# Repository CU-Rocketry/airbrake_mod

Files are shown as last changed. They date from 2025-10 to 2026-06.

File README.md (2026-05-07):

# Air Brakes
The Air Brakes control system primarily manages the vehicle’s energy state throughout its unpowered ascent phase of 
flight by modulating the rocket’s aerodynamic drag profile in a bid to regulate its apogee to the specified target of 
10,000 ft AGL with a tolerance of ± 500 ft. At the 2025 IREC, Clarkson University Rocketry (CUR) launched Veðrfölnir, 
last year’s rocket and Air Brakes iteration, to an apogee of 10,352 ft, successfully achieving our apogee target goal. 
This year, CUR returns with the improvements detailed below with the intention of again improving our apogee accuracy through further control system development.

The complete Air Brakes system includes a mechanical assembly engineered for fail-safe, symmetric brake flap deployment, a refined electronics hardware design, 
and an improved control algorithm responsible for state estimation of the rocket, apogee prediction, and continuously variable PI-controller generating actuation commands. 
Throughout the development cycle, the team focused on building off of prior successes and expanding novel concepts, while ensuring Air Brakes safety and working 
within manufacturability and integration constraints.

## Mechanical Design
The Air Brakes mechanical design source files are not included in this repository.

The design features four symmetrically arranged brake flaps whcih are deployed radially into the airstream surrounding the rocket body. 
The current revision has a total wetted area of 10.18 in², resulting in a near doubling of the total drag force on the rocket to a maximum of 222.6 lbf if deployed after burnout.
The brake flaps ride along linear rails to bear the aerodynamic load and are deployed by a high-speed, high-torque, and dust-rated servo motor, which rotates a central hub connected by linkages to the flaps. 
The chosen servo was tested under load to fully deploy in only 0.3 seconds, and has been upgraded since last year with a feedback signal allowing the microcontroller to measure true deployment as well as detect and mitigate brake flap binding. 
The system continues to integrate compactly within the rocket airframe, adding only 1.75 in to the rocket’s overall length while featuring an increased upper coupler bonded length of 2 in.

Prior revisions of the Air Brakes module have been flown at the Spaceport America Cup and Midland, TX Interneational Rocket Engineering Competition (IREC) events.

## Control System PCB
KiCad 9 source files for the control system PCB are included within the `pcb/` directory. A hierarchical structure is used for schematic diagrams, and schematic symbols as well as PCB footprints
created by the team or downloaded from the manufacturer are included within the `pcb/kicad-library` submodule, which may need to be synced as part of the setup process.

The air brakes electronics feature a four layer, single sided control system PCB with the following considerations taken to achieve our safety critical design constraints while implementing an STM32H730 MCU to perform state estimation and control system tasks, handle user interface, and command the brake flap actuation servo.
The PCB form factor has changed since the revision flown at IREC 2025: the 18650 battery holders have been removed in favor of an externally connected battery, allowing the board size to be halved and battery located beside the PCB.

Power for the system is supplied by a 7.4V (2S) 3000 mAh lithium-ion battery connected to the board by an XT30 connector.
The system has a power-on battery life of at least 12 hr based on battery current draw measurements for an onboard shunt resistor-based current monitor IC.
System power status is determined using an on-chip ADC peripheral of the MCU, reading both the current sense IC output and level of a 2.75:1 voltage divider to convert the battery voltage to fit within the ADC's 3.3V range.

This control system PCB includes power distribution to the servo motor, which may be switched on or off by an on-board transistor under software control.
The servo motor is connected with a four pin latching connector.
As an iterative improvement to our prior design with experience from IREC 2025, the servo has been substituted for an otherwise similar model with position feedback on an additional wire carrying an analog voltage signal corresponding to the servo shaft angle, which may be read by the MCU with an ADC peripheral.

The system includes multiple physical controls including an on-off slide switch, an eight-position rotary mode selector switch, and four tactile switches with alternative functionality based on current mode.
Available modes include startup, testing of user interface, servo, flash, sensors, and control system, a launch detect state to be enabled at the pad, and a data offloading state.
The power switch controls the buck converter enable signal, and includes an RC (resistor-capacitor) filter (time constant tau=0.135 s) to prevent switch bouncing from temporarily disabling the buck converter and resetting the system.
In addition, two RGB LEDs and a passive buzzer (allowing for frequency control) are implemented on the PCB to give internally and externally accessible go/no-go feedback.

To act as inputs to the control system, MEMS sensors from STMicroelectronics were chosen for their pre-existing driver compatibility with STM32 MCUs.
Each sensor also has commonality with the SRAD flight computer developed in parallel, allowing electrical schematics, PCB layout, and code to be shared between the systems towards integrating them in the future.
The LPS22DF barometer was chosen for its 24 bit at 200 Hz pressure output capability, and 22,000G shock survivability. A new inertial measurement unit (IMU), the LSM6DSV80X, was selected for its dual 16 bit accelerometer channels: a low-G channel measuring up to 16G and high-G channel measuring up to 80G in addition to including a 4000 dps, 16 bit gyroscope. 
Together with the final sensor, an IIS2MDC 16 bit magnetometer compass IC, a full complement 9-axis IMU can be implemented in software.

The control system PCB retains a USB Type-C connector for power and data transfer, as well as an on-board 128 MBit flash memory, which emulates a USB flash drive when plugged into a computer in data offloading mode.

## State Estimation and Control System

The air brakes control system was prototyped as a subsystem within the rocket plant Simulink model, which was
later ported to C code to run on the air brakes system’s MCU, taking advantage of the device’s double precision FPU
(Floating Point Unit) as well as using ARM-optimized CMSIS-DSP functions for matrix processing. For clarity and
brevity, the control system functionality is described in this report referencing the Simulink model.
Factoring in the orientation of the implemented sensors on the PCB relative to the body frame was crucial for the
interpretation of IMU and magnetometer data. Unit conversions were also implemented in this sensor data pre-processing step using conversion
factors to common SI units.
The state estimation subsystem implements Madgwick filter sensor fusion on IMU and magnetometer data to
estimate a body to inertial quaternion rotation. The magnetometer assists in estimating the orientation of the rocket by
recording magnetic flux density to the end of determining the magnetic north direction, though it contributes to the
Madgwick filter at a slower update rate through a separate function due to its limited ODR (Output Data Rate). This
quaternion is normalized to a unit vector, and a vector rotation is then performed, where the rotated vector represents 
estimated acceleration in the inertial frame, a necessary input to the next stage of the
control system: the Kalman filter. A two-state Kalman filter was implemented to estimate the rocket’s current altitude
and vertical velocity, and in a similar way to the Madgwick filter, the Kalman filter is implemented as two separate
functions to allow the prediction step—based on high-ODR accelerometer data—to be decoupled from the correction
step which relies on the slower barometer data updates.
The final component of the state estimation subsystem, a launch detect function, was incorporated to identify the
beginning of flight, and differentiate between unintentional movement of the rocket and actual launch. If the rocket
experiences a significant acceleration in the body +X direction and increase in barometric altitude, launch detect is
triggered. When launch detect is triggered, the time since system power on is stored as the launch time, and the mission
elapsed time afterwards is calculated by subtracting the launch time from the time since power on.
The air brakes control system relies on the data from the Kalman filter to predict the rocket’s eventual apogee
using a simplified lightweight model for a projectile with drag, which is used (when the target apogee is subtracted) as the
error input to the controller.
The air brakes deployment controller follows a typical PID (Proportional-Integral-Derivative) structure, but with the
derivative component removed (i.e. gain set to zero) to avoid over correction or oscillation that may make achieving
the target apogee impossible. Instead, small Kp and Ki gains are used to drive the servo motor to decrease the error
function, which is calculated as the difference between the predicted apogee and 3048 m target apogee. The integral
term includes both anti-windup protection, limiting its contribution to deployment to a maximum of 50% and also
resetting the integral term any time the predicted apogee is below the target apogee.
An air brakes lockout subsystem places checks on the controller’s output to the brake actuation servo, preventing
deployment or retracting the brakes if the rocket is still in the powered ascent phase of flight, if the vertical
velocity is slow and the air brakes are ineffective, or if the rocket’s attitude exceeds 30◦ from launch elevation.

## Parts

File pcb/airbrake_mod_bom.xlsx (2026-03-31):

Reference | Qty | MPN
BZ1 | 1 | CEM-1203(42)
C1,C2 | 2 | GRT188R61H225KE13D
C3,C26 | 2 | GRM188R61E475KE11D
C4,C9 | 2 | CL10C150JB8NNNC
C5,C7,C8,C10,C11,C13,C14,C15,C20,C23,C24,C25,C27,C28,C29,C31 | 16 | CL10B104KB8NNWC
C6,C12,C18 | 3 | CL10A105KA8NNNC
C16,C22 | 2 | CL21A226MAYNNNE
C17 | 1 | CL10B104KB8NNWC
C19 | 1 | CL10B104KB8NNWC
C21 | 1 | CL10C100JB8NNNC
C30 | 1 | CL10A224KB8NNNC
C32 | 1 | ZRB18AR61C106ME01L
D1,D4 | 2 | SS12
D2,D8,D9 | 3 | FC-1608SXK-620H08
D3,D5 | 2 | 19-237/R6GHBHC-M01/2T
D6,D7 | 2 | ESDA5V3SC5
FB1 | 1 | BLM18AG601SN1D
J1 | 1 | XT30PW-M
J2 | 1 | UJ20-C-H-G-SMT-P16-TR
J3 | 1 | 0436500415
J4 | 1 | 2147511041
J6 | 1 | 3220-14-0100-00
L1 | 1 | SLO0624H3R3MTT
Q1,Q2,Q4,Q6 | 4 | NTR4003N
Q3,Q5 | 2 | SI3407DV-T1-GE3
R1 | 1 | RC0603FR-0747RL
R2,R4,R8,R9,R11,R16,R22,R23,R24,R26,R28,R33,R40,R41,R42 | 15 | RC0603FR-0747KL
R3,R5,R10,R19,R20,R21,R25,R27,R29,R30,R31,R35,R36,R39,R43,R44 | 16 | RC0603JR-07150RL
R6 | 1 | RC0603FR-0747KL
R7 | 1 | RC0603FR-0782KL
R12 | 1 | RT0603BRD07135KL
R13,R15 | 2 | AC0603FR-0730KL
R14 | 1 | PA0805FRE7W0R002L
R17,R18 | 2 | RC0603FR-075K1L
R32,R34,R37,R38 | 4 | RC0603FR-0747RL
S1 | 1 | RDS4-8S-1012-73-RA-254-D-67
SW1,SW2,SW4,SW5,SW6,SW7 | 6 | SKRPADE010
SW3 | 1 | SLW-864574-5A-RA-N-D
TP1,TP2,TP3,TP4,TP5,TP6,TP7,TP8,TP9,TP10,TP11,TP12,TP13,TP14,TP15,TP16,TP17,TP18,TP19,TP20,TP21,TP22,TP23,TP24,TP25,TP26,TP27,TP28,TP29,TP30,TP31,TP32,TP33,TP34,TP35,TP36,TP37 | 37 | RCUCTE
U1 | 1 | STM32H730VBT6
U2 | 1 | TPS561246DRLR
U3 | 1 | ZXCT180A4W5
U4 | 1 | USBLC6-2SC6
U5 | 1 | W25Q128JVSIQ
U6 | 1 | LPS22DFTR
U7 | 1 | LSM6DSV80XTR
U8 | 1 | IIS2MDCTR
Y1 | 1 | ECS-160-12-33B2Q-JES-TR3

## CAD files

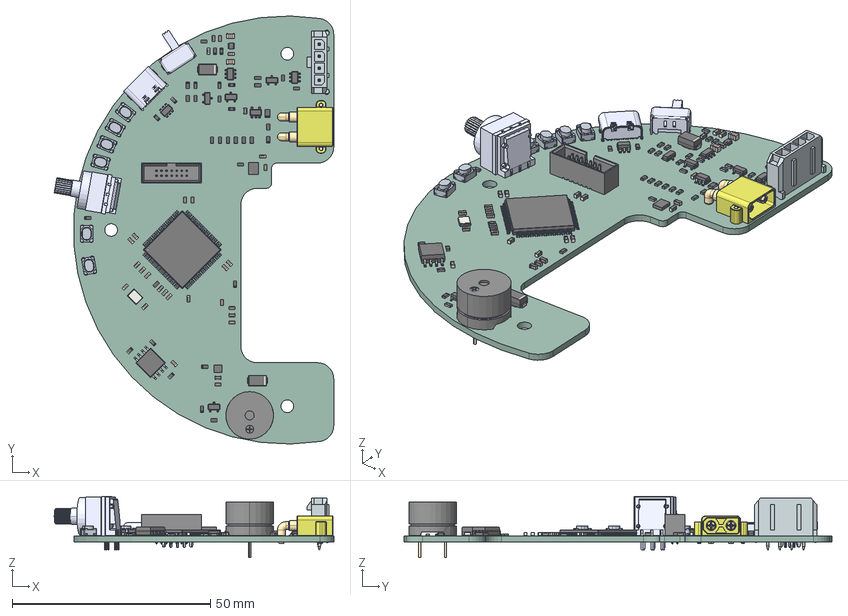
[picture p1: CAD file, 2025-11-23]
pcb/airbrake_mod.step
70.5 x 107.9 x 15.4 mm
C_0603_1608Metric x 28
R_0603_1608Metric x 35
PTS815SJM250SMTRLFS_PART1 x 6
PTS815SJM250SMTRLFS_PART2 x 6
PTS815SJM250SMTRLFS_PART3 x 6
C_0805_2012Metric x 2
Crystal_SMD_3225-4Pin_3.2x2.5mm
TSOP-6_1.65x3.05mm_P0.95mm x 2
L_0603_1608Metric
SOT-23-6
D_SMA x 2
SOT-23-3 x 4
R_0805_2012Metric
SOIC-8_5.3x5.3mm_P1.27mm
kicad_embedded_C4738336200E169EB35A505B1D9200E8
UJ20-C-H-G-SMT-P16-TR
Molex_436500415
LGA-14_3x2.5mm_P0.5mm_LayoutBorder3x4y
SOT-563
RDS4-1012-73-RA HOUSING
RDS4-1012-73-RA-254 HOUSING
RDS4-73-8 POSITION
Buzzer_SameSky_CEM-1203_42
3220-xx-0100-00 body_14
Pin^3220-xx-0100-00 x 14
LQFP-100_14x14mm_P0.5mm
ST_HLGA-10_2x2mm_P0.5mm_LayoutBorder3x2y
SOT-23-5
XT30PW-M
airbrake_mod_PCB

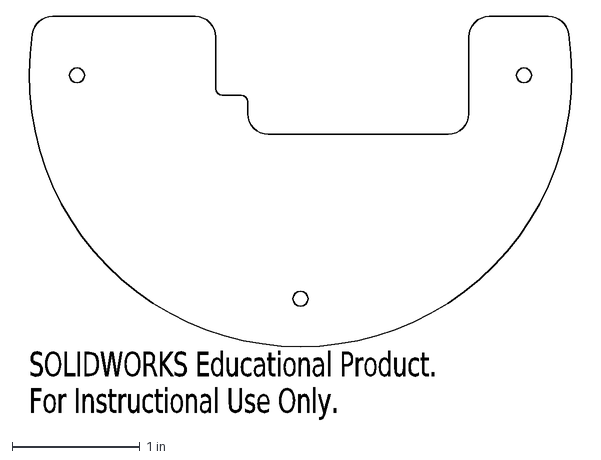
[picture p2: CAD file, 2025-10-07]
pcb/outline.dxf
SOLIDWORKS Educational Product.
For Instructional Use Only.

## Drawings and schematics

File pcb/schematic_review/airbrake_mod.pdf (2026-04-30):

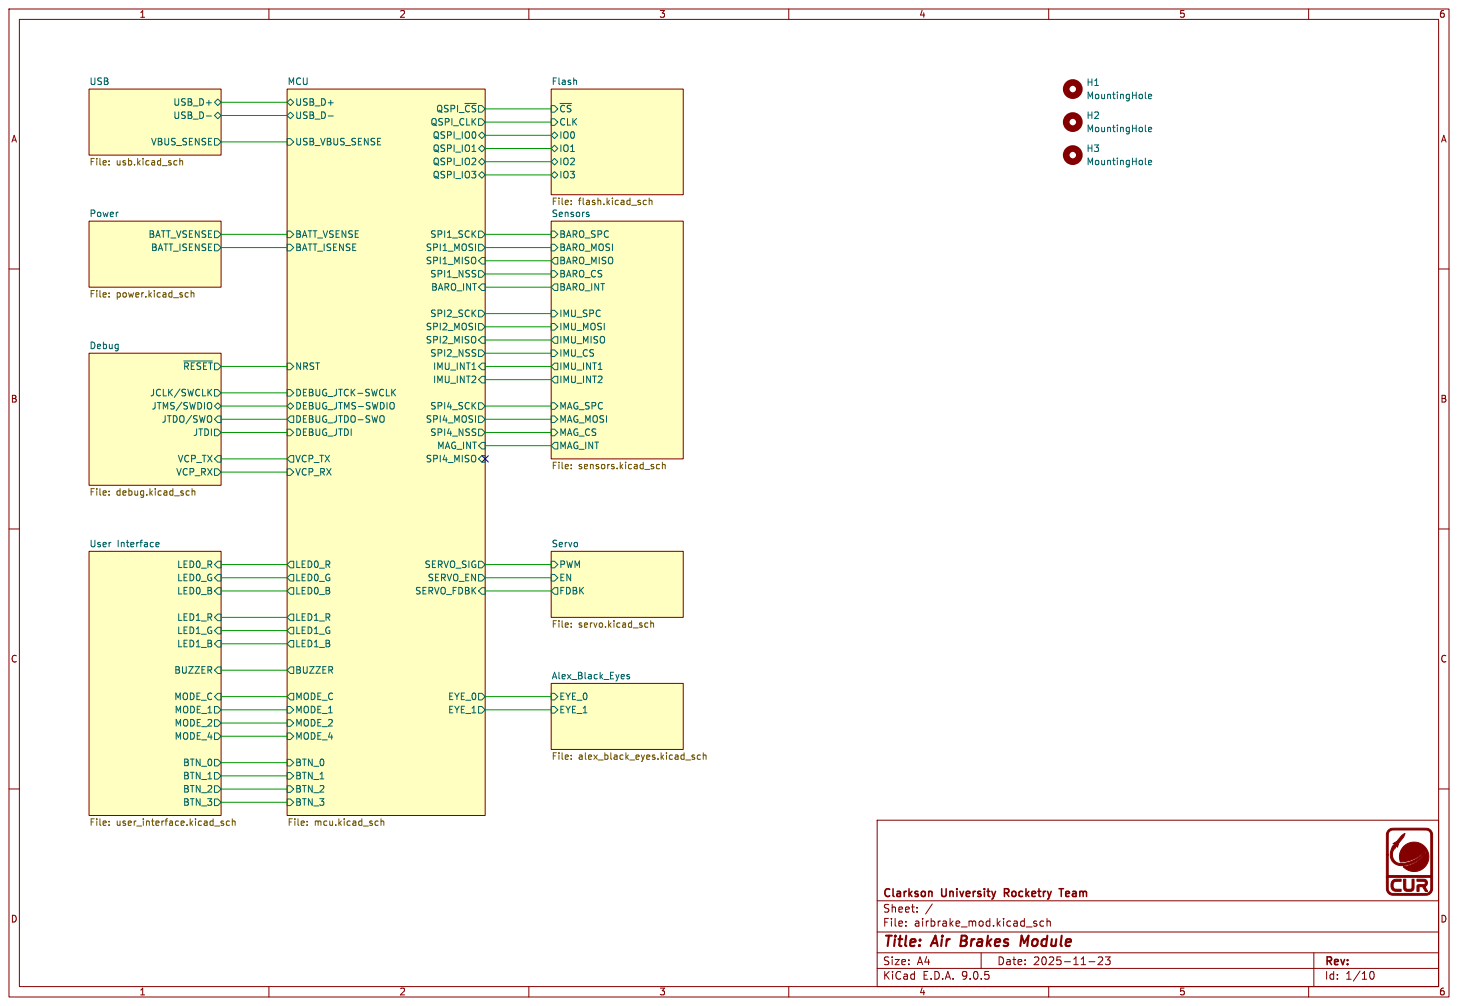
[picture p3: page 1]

Servo File: servo.kicad_sch EYE_1 EYE_0 Alex_Black_Eyes File: alex_black_eyes.kicad_sch

Id: 1/10 Title: Air Brakes Module

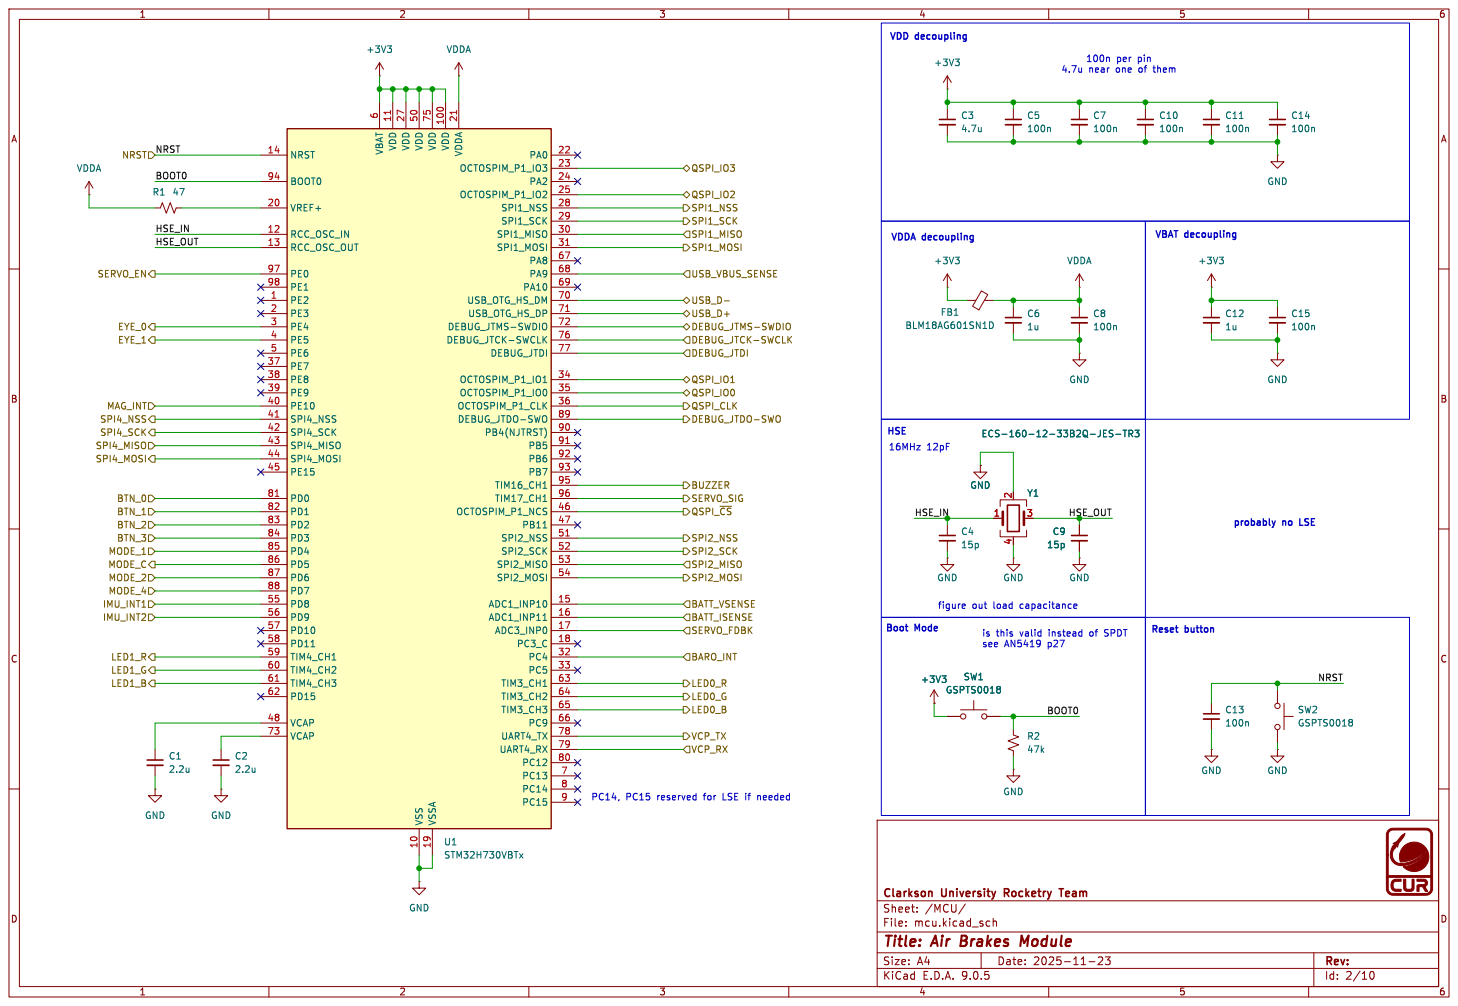
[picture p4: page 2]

100n per pin
4.7u near one of them

VBAT decoupling Boot Mode HSE

16MHz 12pF PC14, PC15 reserved for LSE if needed

is this valid instead of SPDT
see AN5419 p27

Id: 2/10 Title: Air Brakes Module

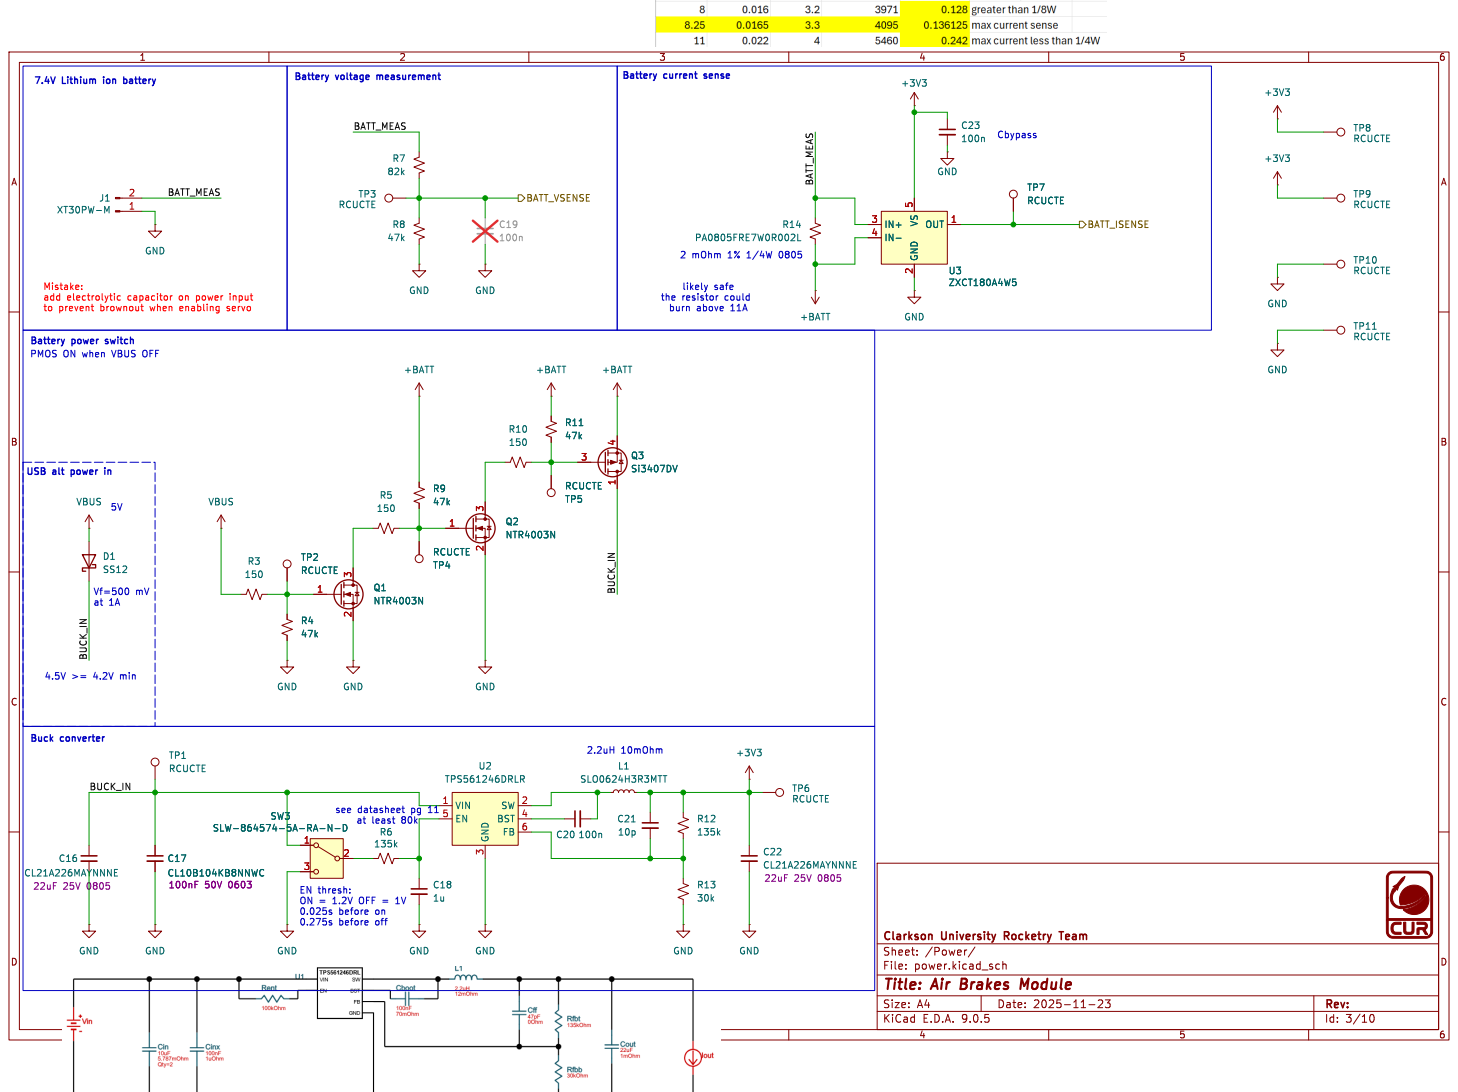
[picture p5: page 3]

USB alt power in PMOS ON when VBUS OFF Battery power switch

at 1A CinC: 20 þÿ¼F- 20 þÿ¼F ESR: 1 þÿm©- 20 þÿm©

at least 80k EN thresh: ON = 1.2V OFF = 1V

Id: 3/10 Title: Air Brakes Module

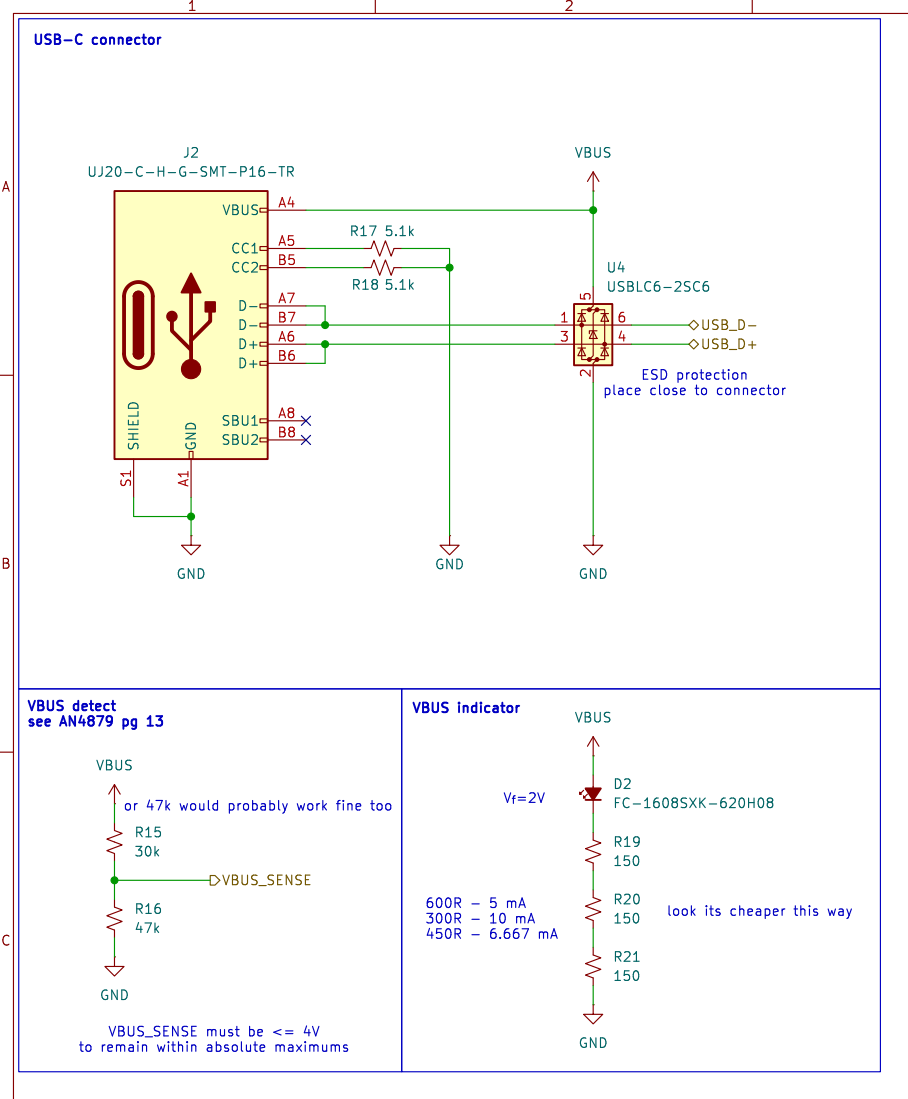
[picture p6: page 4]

look its cheaper this way ESD protection

Id: 4/10 Title: Air Brakes Module

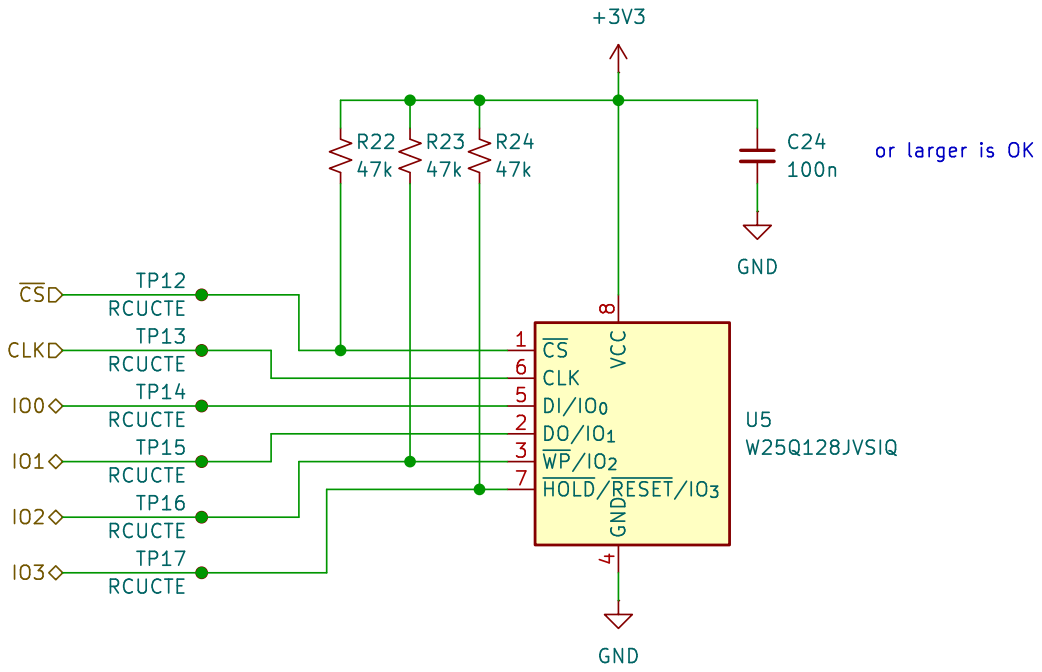
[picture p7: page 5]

or larger is OK

Id: 5/10 Title: Air Brakes Module

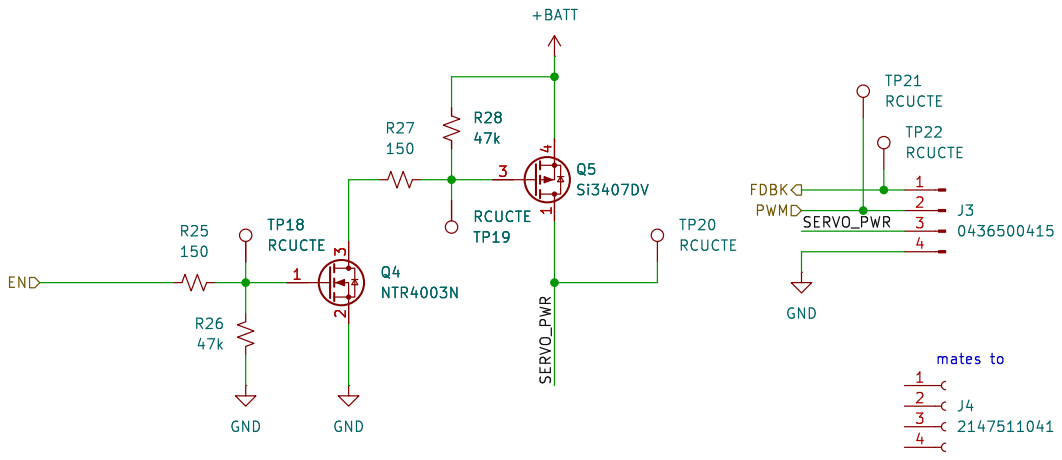
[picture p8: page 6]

Id: 6/10 Title: Air Brakes Module

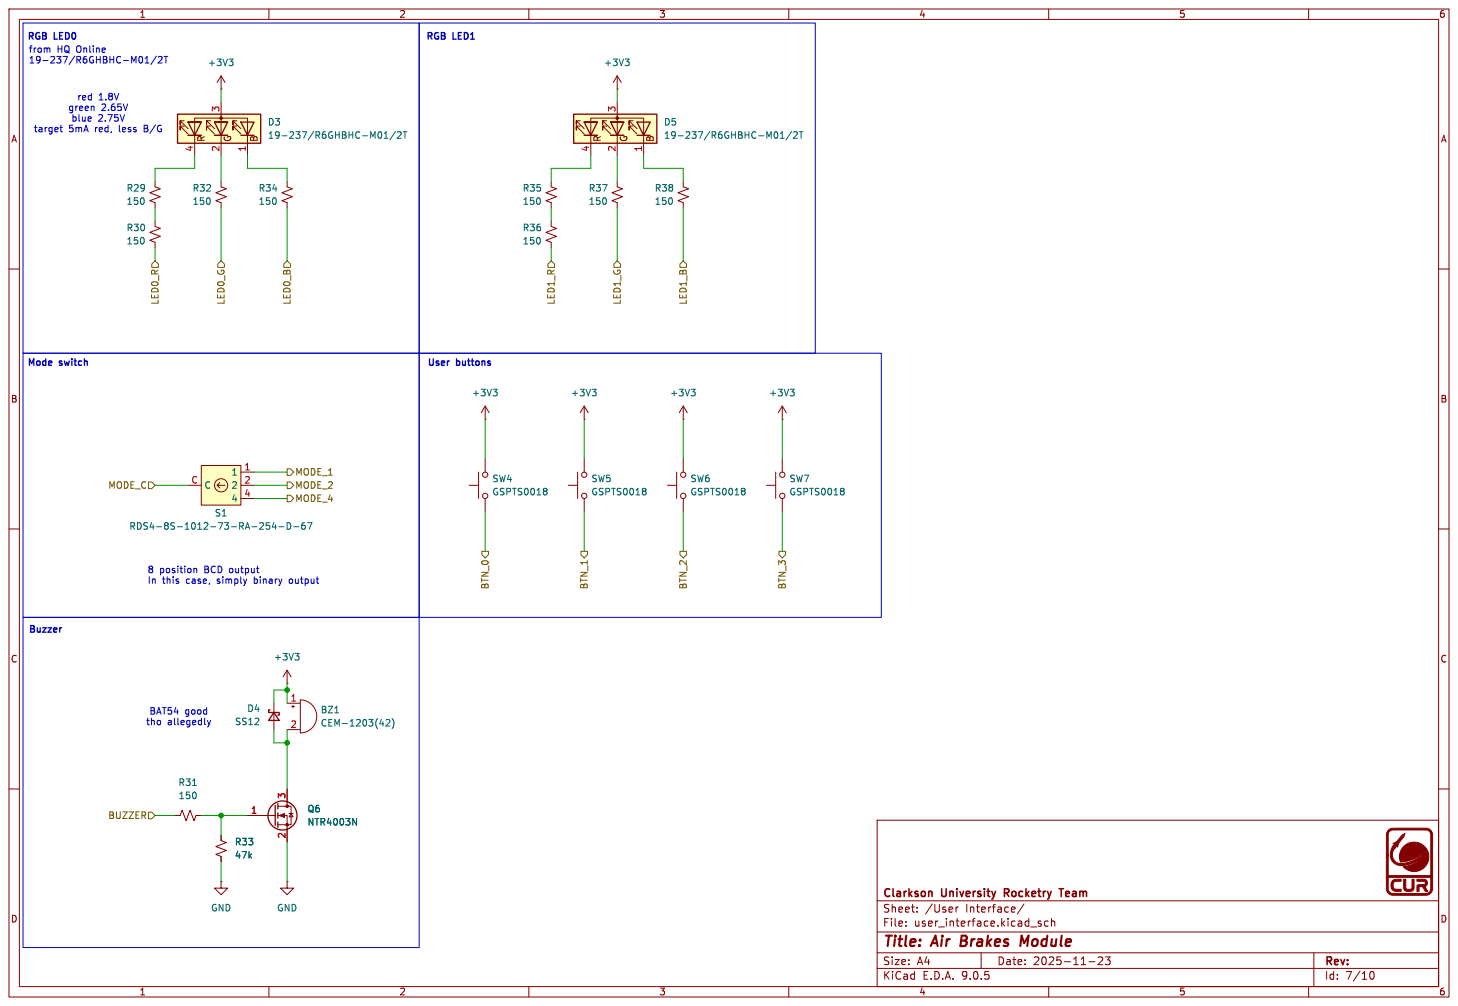
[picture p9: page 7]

tho allegedly Mode switch RGB LED0

In this case, simply binary output Q6 NTR4003N

Id: 7/10 Title: Air Brakes Module

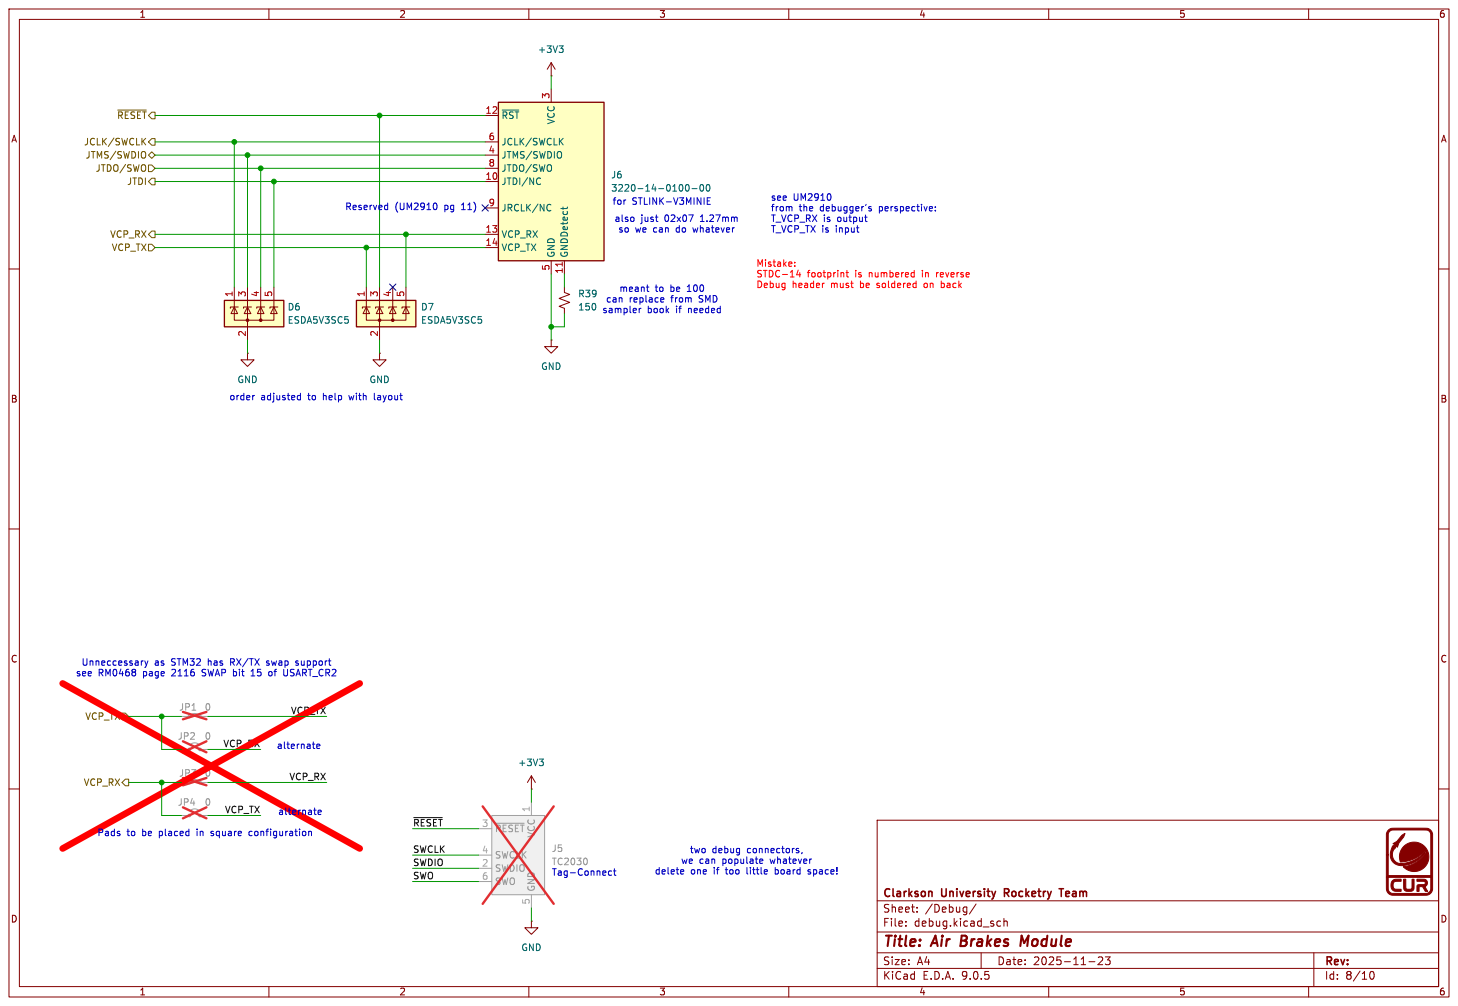
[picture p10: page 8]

meant to be 100
can replace from SMD

5 ~{RESET} 3 SWCLK 4 SWDIO 2 SWO 6

Id: 8/10 Title: Air Brakes Module

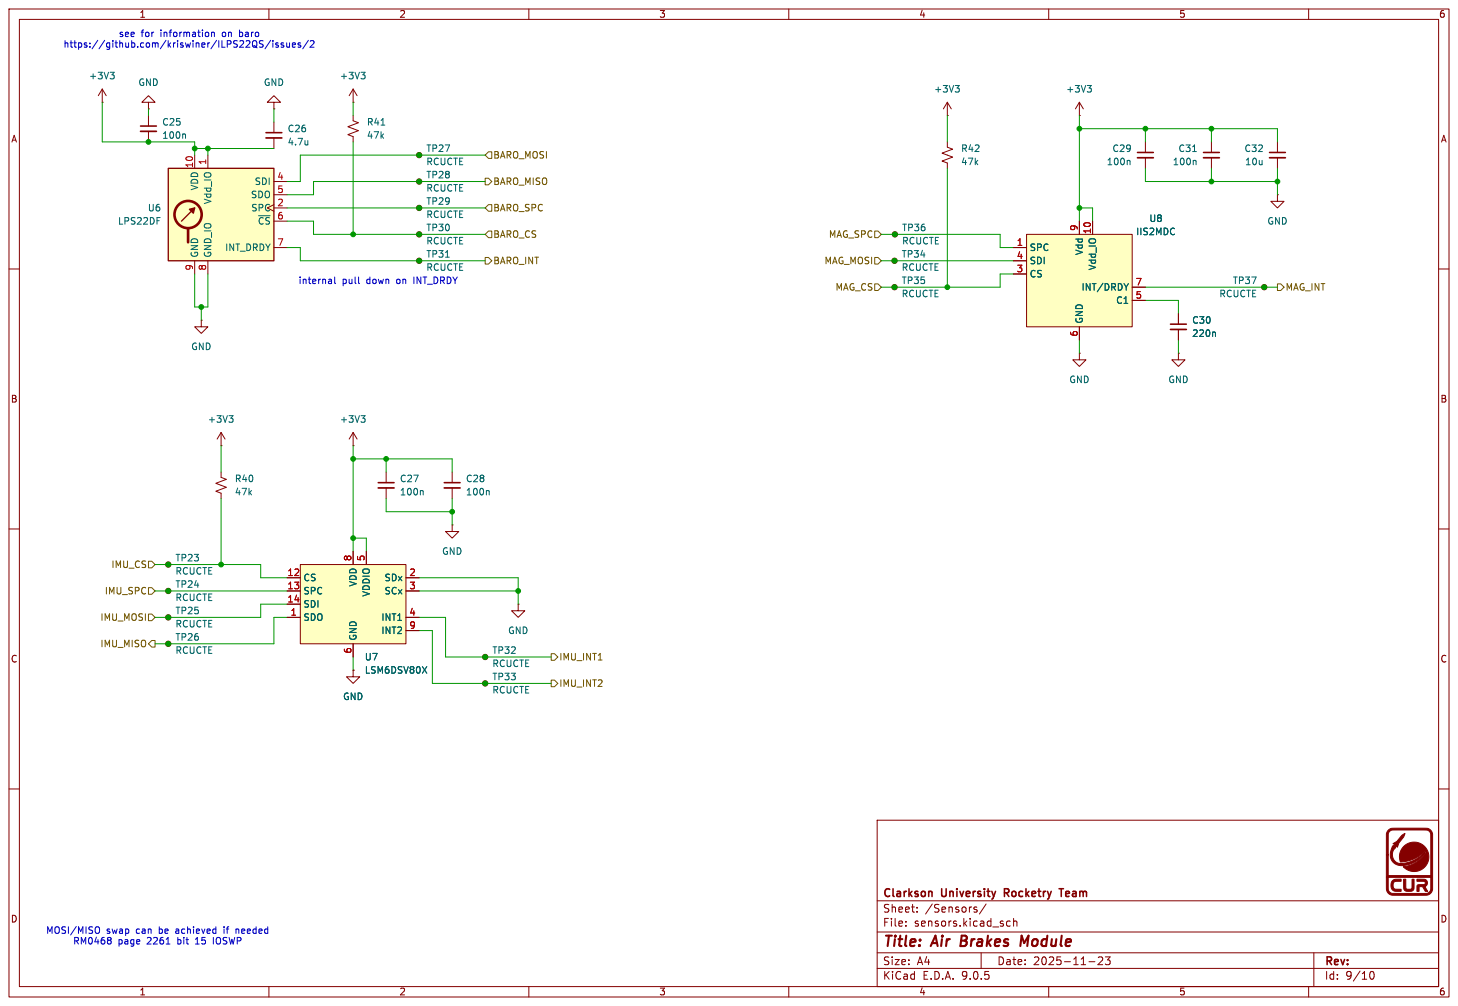
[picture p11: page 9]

8 SDI 4 SDO 5 SPC 2 ~{CS}6

Id: 9/10 Title: Air Brakes Module

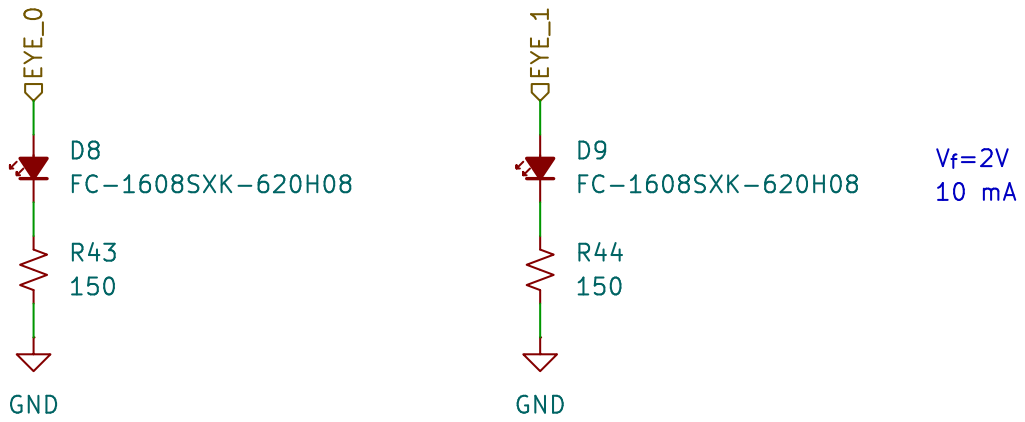
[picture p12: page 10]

Id: 10/10 Title: Air Brakes Module

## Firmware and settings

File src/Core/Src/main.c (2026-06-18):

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
/* Includes ------------------------------------------------------------------*/
#include "main.h"

/* USER CODE BEGIN Includes */
#include "sensors.h"
#include <stdio.h>
#include <string.h>
#include "black_eyes.h"
#include "rgb_led.h"
#include "buzzer.h"
#include "servo.h"
#include "mode_switch.h"
#include "state_estimation.h"
#include "state.h"
#include "batt_sense.h"
#include "telemetry.h"
#include "flash.h"
#include "control.h"
#include "packets.h"
#include "btn.h"
#include "timing.h"
/* USER CODE END Includes */

ADC_HandleTypeDef hadc1;
ADC_HandleTypeDef hadc3;
DMA_HandleTypeDef hdma_adc1;
DMA_HandleTypeDef hdma_adc3;

OSPI_HandleTypeDef hospi1;
MDMA_HandleTypeDef hmdma_octospi1_fifo_th;

SPI_HandleTypeDef hspi1;
SPI_HandleTypeDef hspi2;
SPI_HandleTypeDef hspi4;
DMA_HandleTypeDef hdma_spi1_rx;
DMA_HandleTypeDef hdma_spi1_tx;
DMA_HandleTypeDef hdma_spi2_rx;
DMA_HandleTypeDef hdma_spi2_tx;
DMA_HandleTypeDef hdma_spi4_rx;
DMA_HandleTypeDef hdma_spi4_tx;

TIM_HandleTypeDef htim2;
TIM_HandleTypeDef htim3;
TIM_HandleTypeDef htim4;
TIM_HandleTypeDef htim6;
TIM_HandleTypeDef htim7;
TIM_HandleTypeDef htim16;
TIM_HandleTypeDef htim17;

UART_HandleTypeDef huart4;
DMA_HandleTypeDef hdma_uart4_tx;
DMA_HandleTypeDef hdma_uart4_rx;

PCD_HandleTypeDef hpcd_USB_OTG_HS;

/* USER CODE BEGIN PV */
// Custom driver contexts
rgb_led_t led0 = {
    .handle = &htim3,
    .channel_r = TIM_CHANNEL_1,
    .channel_g = TIM_CHANNEL_2,
    .channel_b = TIM_CHANNEL_3,
	.brightness_shift = 2
};
rgb_led_t led1 = {
    .handle = &htim4,
    .channel_r = TIM_CHANNEL_1,
    .channel_g = TIM_CHANNEL_2,
    .channel_b = TIM_CHANNEL_3,
	.brightness_shift = 2
};
buzzer_t buzzer = {
    .handle = &htim16,
    .tim_freq = 64000000,
    .seq = 0,
    .seq_len = 0,
    .seq_idx = 0,
    .beep_start = 0,
    .seq_playing = 0
};

const buzzer_beep_t seq_startup_3[] = {
	{4186, 250},
	{4435, 250},
	{4699, 500}
};

const buzzer_beep_t seq_mode_1_1[] = {
		{4186, 250}
};

const buzzer_beep_t seq_mode_2_3[] = {
		{4186, 250},
		{0, 250},
		{4186, 250}
};

const buzzer_beep_t seq_mode_3_5[] = {
		{4186, 250},
		{0, 250},
		{4186, 250},
		{0, 250},
		{4186, 250}
};

const buzzer_beep_t seq_mode_4_7[] = {
		{4186, 250},
		{0, 250},
		{4186, 250},
		{0, 250},
		{4186, 250},
		{0, 250},
		{4186, 250}
};

const buzzer_beep_t seq_mode_5_9[] = {
		{4186, 250},
		{0, 250},
		{4186, 250},
		{0, 250},
		{4186, 250},
		{0, 250},
		{4186, 250},
		{0, 250},
		{4186, 250}
};

const buzzer_beep_t seq_mode_6_11[] = {
		{4186, 250},
		{0, 250},
		{4186, 250},
		{0, 250},
		{4186, 250},
		{0, 250},
		{4186, 250},
		{0, 250},
		{4186, 250},
		{0, 250},
		{4186, 250}
};

const buzzer_beep_t seq_mode_7_13[] = {
		{4186, 250},
		{0, 250},
		{4186, 250},
		{0, 250},
		{4186, 250},
		{0, 250},
		{4186, 250},
		{0, 250},
		{4186, 250},
		{0, 250},
		{4186, 250},
		{0, 250},
		{4186, 250}
};

const buzzer_beep_t seq_launch_detect_beep_5[] = {
		{4186, 100},
		{0, 50},
		{4186, 100},
		{0, 50},
		{4186, 100}
};

const buzzer_beep_t seq_apogee_detect_2[] = {
	{4186, 200},
//	{4435, 200},
	{4699, 200}
};


__attribute__((section(".bdma_buf"))) volatile uint16_t servo_dma_buf[1];
servo_t servo = {
	.tim_handle = &htim17,
	.en_gpio_port = SERVO_EN_GPIO_Port,
	.en_pin = SERVO_EN_Pin,
	.adc_handle = &hadc3,
	.dma_buf = servo_dma_buf,
	.duty_retracted = 700,
	.duty_extended = 1980
};
uint8_t endpoint_selected = 0;

batt_sense_t batt_sense = {
	.adc_handle = &hadc1,
	.dma_buf = {0, 0}
};

telemetry_t telemetry = {
    .handle = &huart4
};

flash_t flash = {
    .hospi = &hospi1,
};

btn_t btns[4]; // BTN0 to BTN4 drivers
mode_switch_t mode_switch;

extern uint8_t baro_ready;
extern uint8_t mag_ready;
extern uint8_t imu_ready;

// Control system ticks
uint8_t tick_100Hz = 0; // bool
uint8_t tick_500Hz = 0; // bool

// Mode selection
enum Mode {
	START = -1,
	IDLE = 0,
	TEST_UI = 1,
	TEST_SIMULINK = 2,
	TEST_SERVO = 3,
	TEST_SENSORS = 4,
	TEST_FLASH = 5,
	TEST_CONTROL = 6,
	LAUNCH_DETECT = 7
};
enum Mode mode = -1;
enum Mode mode_prev = -1;
/* USER CODE END PV */

void SystemClock_Config(void);
void PeriphCommonClock_Config(void);
static void MPU_Config(void);
static void MX_GPIO_Init(void);
static void MX_DMA_Init(void);
static void MX_BDMA_Init(void);
static void MX_MDMA_Init(void);
static void MX_USB_OTG_HS_PCD_Init(void);
static void MX_OCTOSPI1_Init(void);
static void MX_UART4_Init(void);
static void MX_SPI2_Init(void);
static void MX_SPI1_Init(void);
static void MX_SPI4_Init(void);
static void MX_TIM16_Init(void);
static void MX_TIM17_Init(void);
static void MX_TIM3_Init(void);
static void MX_TIM4_Init(void);
static void MX_ADC1_Init(void);
static void MX_ADC3_Init(void);
static void MX_TIM7_Init(void);
static void MX_TIM6_Init(void);
static void MX_TIM2_Init(void);
/* USER CODE BEGIN PFP */
// printf UART
#define PUTCHAR_PROTOTYPE int __io_putchar(int ch)

int32_t platform_write(void *handle, uint8_t reg, const uint8_t *bufp, uint16_t len);
int32_t platform_read(void *handle, uint8_t reg, uint8_t *bufp, uint16_t len);
void platform_delay(uint32_t millisec);

// State transitions
void mode_transition_handler(enum Mode prev, enum Mode curr);
void mode_current_handler(enum Mode curr);
/* USER CODE END PFP */

/**
  * @brief  The application entry point.
  * @retval int
  */
int main(void)
{

  /* MPU Configuration--------------------------------------------------------*/
  MPU_Config();

  /* MCU Configuration--------------------------------------------------------*/

  /* Reset of all peripherals, Initializes the Flash interface and the Systick. */
  HAL_Init();

  /* Configure the system clock */
  SystemClock_Config();

  /* Configure the peripherals common clocks */
  PeriphCommonClock_Config();

  /* Initialize all configured peripherals */
  MX_GPIO_Init();
  MX_DMA_Init();
  MX_BDMA_Init();
  MX_MDMA_Init();
  MX_USB_OTG_HS_PCD_Init();
  MX_OCTOSPI1_Init();
  MX_UART4_Init();
  MX_SPI2_Init();
  MX_SPI1_Init();
  MX_SPI4_Init();
  MX_TIM16_Init();
  MX_TIM17_Init();
  MX_TIM3_Init();
  MX_TIM4_Init();
  MX_ADC1_Init();
  MX_ADC3_Init();
  MX_TIM7_Init();
  MX_TIM6_Init();
  MX_TIM2_Init();
  /* USER CODE BEGIN 2 */
  //printf("System reset\r\n");
    telemetry_init(&telemetry);
    telemetry_log(LOG_LVL_DEBUG, "System reset\r\n");

    black_eye_set(0, 0);
    black_eye_set(1, 0);

    rgb_led_init(&led0);
    rgb_led_init(&led1);
    rgb_led_set(&led0, 0x006000);
    rgb_led_set(&led1, 0x0000A0);

    btn_init(&btns[0], BTN_0_GPIO_Port, BTN_0_Pin);
	btn_init(&btns[1], BTN_1_GPIO_Port, BTN_1_Pin);
	btn_init(&btns[2], BTN_2_GPIO_Port, BTN_2_Pin);
	btn_init(&btns[3], BTN_3_GPIO_Port, BTN_3_Pin);

	mode_switch_init(&mode_switch);
	mode = mode_switch_get(&mode_switch);

    batt_sense_init(&batt_sense);

    buzzer_init(&buzzer);

    servo_init(&servo);
    servo_set_duty(&servo, 500);
    servo_enable(&servo, 0);

    sensors_init();

    flash_init(&flash);

  	HAL_TIM_Base_Start_IT(&htim7); // start 100 Hz
    HAL_TIM_Base_Start_IT(&htim6); // start 500 Hz
    HAL_TIM_Base_Start(&htim2); // start microsecond counter

	telemetry_log(LOG_LVL_DEBUG, "Init done\r\n");
  /* USER CODE END 2 */

  /* Infinite loop */
  /* USER CODE BEGIN WHILE */
  while (1)
  {
	  telemetry_rx_poll(&global_state);

	  flash_process();

	  if (tick_100Hz) {
		  tick_100Hz = 0;

		  batt_sense_get(&batt_sense, &(global_state.batt_v), &(global_state.batt_i)); // Read power info

		  servo_get_angle(&servo); // Servo feedback

		  // Button driver state updates for current state and edge detection
		  btn_update(&btns[0]);
		  btn_update(&btns[1]);
		  btn_update(&btns[2]);
		  btn_update(&btns[3]);

		  buzzer_update(&buzzer); // buzzer

		  global_state.t = HAL_GetTick(); // t in ms seems reasonable

		  mode_switch_update(&mode_switch); // driver state updates

		  // Mode selection
		  enum Mode mode_switch_val = (enum Mode)mode_switch_get(&mode_switch); // mode selection from physical switch
		  enum Mode mode_selected = STATE_FLAG_GET(FLAG_MODE_OVERRIDE_EN) ? (enum Mode)global_state.mode_override : mode_switch_val; // choose between control panel override and switch

		  if (mode_selected != mode_prev) {
			  mode_transition_handler(mode_prev, mode_selected);
			  mode_prev = mode_selected;
		  }
		  mode = mode_selected;
		  mode_current_handler(mode);

		  if (mode != TEST_FLASH) {
			  telemetry_packet(&global_state); // sending telemetry last in case a log needs to be sent before (we will drop a frame ig)
		  }
	  }

	  if (tick_500Hz) {
		  tick_500Hz = 0;

		  global_state.t = HAL_GetTick(); // [ms]
		  global_state.elapsed_t = global_state.t - global_state.launch_t;

		  if (mode != TEST_SIMULINK) {
			  state_estimation();
		  }
	  }

    /* USER CODE END WHILE */

    /* USER CODE BEGIN 3 */
  }
  /* USER CODE END 3 */
}

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
/* USER CODE BEGIN 4 */

/**
  * @brief  Retargets the C library printf function to the USART.
  *   None
  * @retval None
  */
PUTCHAR_PROTOTYPE
{
  /* Place your implementation of fputc here */
  /* e.g. write a character to the USART1 and Loop until the end of transmission */
  HAL_UART_Transmit(&huart4, (uint8_t *)&ch, 1, 0xFFFF);

  return ch;
}

void HAL_GPIO_EXTI_Callback(uint16_t GPIO_Pin)
{
//	printf("EXTI:%u\r\n", GPIO_Pin);
	if (GPIO_Pin == BARO_INT_Pin) {
		baro_int_drdy_handler();
	} else if(GPIO_Pin == IMU_INT1_Pin || GPIO_Pin == IMU_INT2_Pin) {
		imu_int_drdy_handler();
	} else if(GPIO_Pin == MAG_INT_Pin) {
		mag_int_drdy_handler();
	}
}

void HAL_SPI_TxRxCpltCallback(SPI_HandleTypeDef *hspi)
{
	if (hspi->Instance == SPI1) {
		baro_spi_callback();
	} else if (hspi->Instance == SPI2) {
		imu_spi_callback();
	}
}

void HAL_SPI_RxCpltCallback(SPI_HandleTypeDef *hspi) {
	if (hspi->Instance == SPI4) {
		mag_spi_callback();
	}
}

void HAL_TIM_PeriodElapsedCallback(TIM_HandleTypeDef *htim) {
	if (htim->Instance == TIM7) { // 100 Hz
		tick_100Hz = 1;
	}
	if (htim->Instance == TIM6) { // 500 Hz (state estimation)
		tick_500Hz = 1;
	}
}

void HAL_UART_ErrorCallback(UART_HandleTypeDef *huart) {
    if (huart->Instance == UART4) {
        telemetry_log(LOG_LVL_ERROR, "HAL_UART_ErrorCallback UART4: %lu", huart->ErrorCode);
    }
}

void HAL_OSPI_ErrorCallback(OSPI_HandleTypeDef *hospi) {
	if (hospi->Instance == OCTOSPI1) {
		telemetry_log(LOG_LVL_ERROR, "HAL_OSPI_ErrorCallback OCTOSPI1: %lu", hospi->ErrorCode);
	}
}

// State
void mode_transition_handler(enum Mode prev, enum Mode curr) {
//	printf("Mode transition from %u to %u\r\n", prev, curr);
	telemetry_log(LOG_LVL_INFO, "Mode transition from %d to %d\r\n", prev, curr);

	// Handle exit from previous mode
	switch (prev) {
		case TEST_SERVO:
			servo_enable(&servo, 0); // Disable servo power
			break;
		case TEST_UI:
			buzzer_set(&buzzer, 0);  // Ensure buzzer is off on exit
			break;
//		case TEST_SIMULINK:
//			HAL_NVIC_EnableIRQ(BARO_INT_EXTI_IRQn);
//			HAL_NVIC_EnableIRQ(IMU_INT1_EXTI_IRQn); // IMU both accel and omega
//			HAL_NVIC_EnableIRQ(MAG_INT_EXTI_IRQn);
//			servo_enable(&servo, 0); // Disable servo power
//			break;
		default:
			break;
	}

	// Play (or dont) buzzer for mode transition
#define BUZZER_ON_TRANSITION
#ifdef BUZZER_ON_TRANSITION
	switch (curr) {
		case 0:
			buzzer_play_sequence(&buzzer, seq_startup_3, 3);
			break;
		case 1:
			buzzer_play_sequence(&buzzer, seq_mode_1_1, 1);
			break;
		case 2:
			buzzer_play_sequence(&buzzer, seq_mode_2_3, 3);
			break;
		case 3:
			buzzer_play_sequence(&buzzer, seq_mode_3_5, 5);
			break;
		case 4:
			buzzer_play_sequence(&buzzer, seq_mode_4_7, 7);
			break;
		case 5:
			buzzer_play_sequence(&buzzer, seq_mode_5_9, 9);
			break;
		case 6:
			buzzer_play_sequence(&buzzer, seq_mode_6_11, 11);
			break;
		case 7:
			buzzer_play_sequence(&buzzer, seq_mode_7_13, 13);
			break;
		default:
			break;
	}
#endif

	// Handle entry to new mode
	switch (curr) {
		case IDLE:
			//buzzer_play_sequence(&buzzer, seq_startup_3, 3);
			telemetry_log(LOG_LVL_DEBUG, "Mode 0 IDLE\r\n");
			break;
		case TEST_UI:
			//buzzer_play_sequence(&buzzer, seq_mode_1_1, 1);
			telemetry_log(LOG_LVL_DEBUG, "Mode 1 TEST_UI\r\n");
			break;
//		case TEST_SIMULINK:
//			buzzer_play_sequence(&buzzer, seq_mode_2_3, 3);
// 			telemetry_log(LOG_LVL_DEBUG, "Mode 2 TEST_SIMULINK\r\n");
//			HAL_NVIC_DisableIRQ(BARO_INT_EXTI_IRQn);
//			HAL_NVIC_DisableIRQ(IMU_INT1_EXTI_IRQn); // IMU both accel and omega
//			HAL_NVIC_DisableIRQ(MAG_INT_EXTI_IRQn);
//			servo_enable(&servo, 1); // Enable servo power
//			break;
		case TEST_SERVO:
			//buzzer_play_sequence(&buzzer, seq_mode_3_5, 5);
			telemetry_log(LOG_LVL_DEBUG, "Mode 3 TEST_SERVO\r\n");
			servo_enable(&servo, 1); // Enable servo power
			servo_set_deployment(&servo, 0);
			break;
		case TEST_SENSORS:
			//buzzer_play_sequence(&buzzer, seq_mode_4_7, 7);
			telemetry_log(LOG_LVL_DEBUG, "Mode 4 TEST_SENSORS\r\n");
			break;
		case TEST_FLASH:
			//buzzer_play_sequence(&buzzer, seq_mode_5_9, 9);
			telemetry_log(LOG_LVL_DEBUG, "Mode 5 TEST_FLASH\r\n");

//			uint32_t flash_id = flash_read_jedec_id(&flash);
//			if (flash_id == W25Q128JV_JEDEC_ID) {
//				printf("JEDEC ID good: 0x%06lX\r\n", flash_id);
//				rgb_led_set(&led0, 0x00FF00); // status LED green
//			} else {
//				printf("JEDEC ID error: 0x%06lX (Expected 0x%06X)\r\n", flash_id, W25Q128JV_JEDEC_ID);
//				rgb_led_set(&led0, 0xFF0000); // status LED red
//			}
//
//			// Test flash erased
//			if (flash_check_erased(&flash)) { // if erased
//				printf("Flash is blank. Ready for flight!\r\n");
//				rgb_led_set(&led0, 0x00FF00); // status LED green
//			} else { // else not erased
//				printf("Flash is NOT erased! Must do so before flight.\r\n");
//				rgb_led_set(&led0, 0xFF0000); // status LED red to indicate needs erasing
//			}

			break;
		case TEST_CONTROL:
			//buzzer_play_sequence(&buzzer, seq_mode_6_11, 11);
			telemetry_log(LOG_LVL_DEBUG, "Mode 6 TEST_CONTROL\r\n");
			break;
		case LAUNCH_DETECT:
			//buzzer_play_sequence(&buzzer, seq_mode_7_13, 13);
			telemetry_log(LOG_LVL_DEBUG, "Mode 7 LAUNCH_DETECT\r\n");
			servo_enable(&servo, 1); // Enable servo power
			servo_set_deployment(&servo, 0);
			lockouts_init(); // TODO maybe also when launch is detected
			break;
		default:
			break;
	}
}

void mode_current_handler(enum Mode curr) {
	switch (curr) {
		case IDLE: // 0
			break;
		case TEST_UI: // 1

			// buzzer test
			if (btn_get_edge(&btns[0]) == 1)
			{
				buzzer_play_sequence(&buzzer, seq_startup_3, 3);
			}

			// btn driver test
			if (btn_get_edge(&btns[1]) == 1)
			{
				telemetry_log(LOG_LVL_DEBUG, "BTN1 pressed");
			}
			if (btn_get_edge(&btns[1]) == -1)
			{
				telemetry_log(LOG_LVL_DEBUG, "BTN1 released");
			}
			break;

//		case TEST_SIMULINK: // 2
//			if (cobs_uart.rx_ready) {
//				if (hil_parse_rx(&cobs_uart, &global_state)) { // Parse and map data
//					imu_ready = 1;
//					mag_ready = 1;
//					baro_ready = 1;
//
//					state_estimation(0.01f); // update alt_agl vel_z and accel_b
//					control_update(0.01f); // 100Hz dt
//					servo_set_deployment(&servo, global_state.output);
//
//					hil_send(&cobs_uart, &global_state); // Encode and return to simulink
//				}
//
//				// Reset RX state for the next packet
//				cobs_uart.rx_idx = 0;
//				cobs_uart.rx_ready = 0;
//			}
//			break;

		case TEST_SERVO: // 3

			if (STATE_FLAG_GET(FLAG_SERVO_OVERRIDE_EN)) { // control panel override
				servo_set_angle(&servo, global_state.servo_cmd_override);
			}
			else if (btn_get_edge(&btns[0]) == 1) // BTN0 goes to retracted endpoint
			{
				servo_set_duty(&servo, servo.duty_retracted);
				endpoint_selected = 0;
				telemetry_log(LOG_LVL_INFO, "Retracted");
			}
			else if (btn_get_edge(&btns[1]) == 1) // BTN1 goes to extended endpoint
			{
				servo_set_duty(&servo, servo.duty_extended);
				endpoint_selected = 1;
				telemetry_log(LOG_LVL_INFO, "Extended");
			}
			else if (btn_get(&btns[2])) // BTN2 decreases deployment of selected endpoint
			{
				if (endpoint_selected == 0) { // retracted
					servo.duty_retracted -= 1;
					servo_set_duty(&servo, servo.duty_retracted);
//					printf("retracted:%lu\r\n", servo.duty_retracted);
					telemetry_log(LOG_LVL_INFO, "retracted:%lu", servo.duty_retracted);
				} else if (endpoint_selected == 1) { // extended
					servo.duty_extended -= 1;
					servo_set_duty(&servo, servo.duty_extended);
//					printf("extended:%lu\r\n", servo.duty_extended);
					telemetry_log(LOG_LVL_INFO, "extended:%lu", servo.duty_extended);
				}
			}
			else if (btn_get(&btns[3])) // BTN3 increases deployment of selected endpoint
			{
				if (endpoint_selected == 0) { // retracted
					servo.duty_retracted += 1;
					servo_set_duty(&servo, servo.duty_retracted);
//					printf("retracted:%lu\r\n", servo.duty_retracted);
					telemetry_log(LOG_LVL_INFO, "retracted:%lu", servo.duty_retracted);
				} else if (endpoint_selected == 1) { // extended
					servo.duty_extended += 1;
					servo_set_duty(&servo, servo.duty_extended);
//					printf("extended:%lu\r\n", servo.duty_extended);
					telemetry_log(LOG_LVL_INFO, "extended:%lu", servo.duty_extended);
				}
			}

			break;

		case TEST_SENSORS: // 4

			printf("mag_x:%f,mag_y:%f,mag_z:%f\r\n",
								global_state.mag_mgauss[0], global_state.mag_mgauss[1], global_state.mag_mgauss[2]);
			break;

		case TEST_FLASH: // 5

			if (HAL_GPIO_ReadPin(BTN_0_GPIO_Port, BTN_0_Pin)) // if BTN0 pressed print CSV over UART
			{
				uint32_t read_address = 0;
				flash_packet_t packet_r;

				// Print CSV Header
				printf("t,elapsed_t,flags,batt_v,batt_i,accel_ms2[0],accel_ms2[1],accel_ms2[2],omega_rads[0],omega_rads[1],omega_rads[2],mag_mgauss[0],mag_mgauss[1],mag_mgauss[2],pres_pa,accel_b[0],accel_b[1],accel_b[2],omega_b[0],omega_b[1],omega_b[2],mag_b[0],mag_b[1],mag_b[2],quat[0],quat[1],quat[2],quat[3],accel_e[0],accel_e[1],accel_e[2],p_ground,alt_agl,vel_z,predicted,output,p_contrib,i_contrib,servo_cmd,servo_fdbk\r\n");

				// read until end or when timestamp in packet is unwritten
				while (read_address < W25Q128JV_SIZE) {
					flash_read_blocking(read_address, (uint8_t*)&packet_r, sizeof(flash_packet_t));

					if (packet_r.t == 0xFFFFFFFF) { // timestamp won't be 0xFFFFFFFF until 50 days so this indicates end of flash writing
						printf("Timestamp 0xFFFFFFFF\r\n");
						// break;
					}

					// Print as CSV row
//							t   el  fla batv bati ax    ay   az   wx   wy   wz  magx magy magz pres abx  aby   abz  wbx  wby wbz  mbx  mby  mbz  q0   q1   q2   q3   aex  aey  aez  pg    alt velz pred out  p    i    cmd  fdbk
					printf("%lu,%lu,%lx,%.3f,%.3f,%.3f,%.3f,%.3f,%.3f,%.3f,%.3f,%.3f,%.3f,%.3f,%.3f,%.3f,%.3f,%.3f,%.3f,%.3f,%.3f,%.3f,%.3f,%.3f,%.3f,%.3f,%.3f,%.3f,%.3f,%.3f,%.3f,%.3f,%.3f,%.3f,%.3f,%.3f,%.3f,%.3f,%.3f,%.3f\r\n",
							packet_r.t,
							packet_r.elapsed_t,

							packet_r.flags,

							packet_r.batt_v,
							packet_r.batt_i,

							packet_r.accel_ms2[0], packet_r.accel_ms2[1], packet_r.accel_ms2[2],
							packet_r.omega_rads[0], packet_r.omega_rads[1], packet_r.omega_rads[2],
							packet_r.mag_mgauss[0], packet_r.mag_mgauss[1], packet_r.mag_mgauss[2],
							packet_r.pres_pa,

							packet_r.accel_b[0], packet_r.accel_b[1], packet_r.accel_b[2],
							packet_r.omega_b[0], packet_r.omega_b[1], packet_r.omega_b[2],
							packet_r.mag_b[0], packet_r.mag_b[1], packet_r.mag_b[2],

							packet_r.quat[0], packet_r.quat[1], packet_r.quat[2], packet_r.quat[3],
							packet_r.accel_e[0], packet_r.accel_e[1], packet_r.accel_e[2],

							packet_r.p_ground,
							packet_r.alt_agl,
							packet_r.vel_z,

							packet_r.predicted,
							packet_r.output,
							packet_r.p_contrib,
							packet_r.i_contrib,

							packet_r.servo_cmd,
							packet_r.servo_fdbk);

					read_address += W25Q_PAGE_SIZE;

					HAL_Delay(1);
				}
				printf("end of flash\r\n");
			}

			else if (HAL_GPIO_ReadPin(BTN_1_GPIO_Port, BTN_1_Pin) == GPIO_PIN_SET) { // if BTN1 pressed test R/W
				// printf("Flash RW test\r\n");
				telemetry_log(LOG_LVL_INFO, "Flash RW test\r\n");

				rgb_led_set(&led1, 0x0000FF); // operating LED blue

				uint32_t test_address = 0x000000; // Sector 0

				flash_packet_t dummy_packet_w = {0}; // test packet to write
				flash_packet_t dummy_packet_r = {0}; // test packet to read back

				dummy_packet_w.t = 1234; // update write state time (first in struct)
				dummy_packet_w.servo_fdbk = 42.0f; // update write state servo fdbk (last in struct)

				// printf("Erase sector 0\r\n");
				telemetry_log(LOG_LVL_DEBUG, "Erase sector 0\r\n");
				flash_erase_sector(test_address);

				// printf("Write %u bytes\r\n", sizeof(flash_packet_t));
				telemetry_log(LOG_LVL_DEBUG, "Write %u bytes\r\n", sizeof(flash_packet_t));
				flash_write_blocking(test_address, (uint8_t*)&dummy_packet_w, sizeof(flash_packet_t));

				printf("Read back\r\n");
				telemetry_log(LOG_LVL_DEBUG, "Read back\r\n");
				memset(&dummy_packet_r, 0, sizeof(flash_packet_t));
				flash_read_blocking(test_address, (uint8_t*)&dummy_packet_r, sizeof(flash_packet_t));

				if (dummy_packet_r.t == dummy_packet_w.t && dummy_packet_r.servo_fdbk == dummy_packet_w.servo_fdbk) {
//					printf("RW test passed with t=%lu and servo_fdbk=%f\r\n", dummy_packet_r.t, dummy_packet_r.servo_fdbk);
					telemetry_log(LOG_LVL_INFO, "RW test passed with t=%lu and servo_fdbk=%f\r\n", dummy_packet_r.t, dummy_packet_r.servo_fdbk);
					rgb_led_set(&led1, 0x00FF00);
				} else {
//					printf("RW test failed with t=%lu and servo_fdbk=%f\r\n", dummy_packet_r.t, dummy_packet_r.servo_fdbk);
					telemetry_log(LOG_LVL_ERROR, "RW test failed with t=%lu and servo_fdbk=%f\r\n", dummy_packet_r.t, dummy_packet_r.servo_fdbk);
					rgb_led_set(&led1, 0xFF0000);
				}

				HAL_Delay(1000);
				rgb_led_set(&led1, 0x000000);
			}

			else if (HAL_GPIO_ReadPin(BTN_2_GPIO_Port, BTN_2_Pin) == GPIO_PIN_SET) { // if BTN2 pressed check if erased
				// Test flash erased
				// Turn off both LEDS
				rgb_led_set(&led0, 0x000000); // status LED
				rgb_led_set(&led1, 0x000000); // operating LED
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

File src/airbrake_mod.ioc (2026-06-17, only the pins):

Mcu.UserName=STM32H730VBTx
PA1.Signal=OCTOSPIM_P1_IO3
PA11.Signal=USB_OTG_HS_DM
PA12.Signal=USB_OTG_HS_DP
PA13(JTMS/SWDIO).Signal=DEBUG_JTMS-SWDIO
PA14(JTCK/SWCLK).Signal=DEBUG_JTCK-SWCLK
PA15(JTDI).Signal=DEBUG_JTDI
PA3.Signal=OCTOSPIM_P1_IO2
PA4.GPIO_Label=BARO_NSS
PA4.Signal=GPIO_Output
PA5.GPIO_Label=BARO_SCK
PA5.Signal=SPI1_SCK
PA6.GPIO_Label=BARO_MISO
PA6.Signal=SPI1_MISO
PA7.GPIO_Label=BARO_MOSI
PA7.Signal=SPI1_MOSI
PA9.Signal=USB_OTG_HS_VBUS
PB0.Signal=OCTOSPIM_P1_IO1
PB1.Signal=OCTOSPIM_P1_IO0
PB10.Signal=OCTOSPIM_P1_NCS
PB12.GPIO_Label=IMU_NSS
PB12.Signal=GPIO_Output
PB13.GPIO_Label=IMU_SCK
PB13.Signal=SPI2_SCK
PB14.GPIO_Label=IMU_MISO
PB14.Signal=SPI2_MISO
PB15.GPIO_Label=IMU_MOSI
PB15.Signal=SPI2_MOSI
PB2.Signal=OCTOSPIM_P1_CLK
PB3(JTDO/TRACESWO).Signal=DEBUG_JTDO-SWO
PB8.GPIO_Label=BUZZER
PB8.Signal=S_TIM16_CH1
PB9.GPIO_Label=SERVO_SIG
PB9.Signal=S_TIM17_CH1
PC0.GPIO_Label=BATT_VSENSE
PC0.Signal=ADCx_INP10
PC1.GPIO_Label=BATT_ISENSE
PC1.Signal=ADCx_INP11
PC10.Signal=UART4_TX
PC11.Signal=UART4_RX
PC2_C.GPIO_Label=SERVO_FDBK
PC2_C.Signal=ADC3_INP0
PC4.GPIO_Label=BARO_INT
PC4.Signal=GPXTI4
PC6.Signal=S_TIM3_CH1
PC7.Signal=S_TIM3_CH2
PC8.Signal=S_TIM3_CH3
PD0.GPIO_Label=BTN_0
PD0.Signal=GPXTI0
PD1.GPIO_Label=BTN_1
PD1.Signal=GPXTI1
PD12.Signal=S_TIM4_CH1
PD13.Signal=S_TIM4_CH2
PD14.Signal=S_TIM4_CH3
PD2.GPIO_Label=BTN_2
PD2.Signal=GPXTI2
PD3.GPIO_Label=BTN_3
PD3.Signal=GPXTI3
PD4.GPIO_Label=MODE_1
PD4.Signal=GPIO_Input
PD5.GPIO_Label=MODE_C
PD5.Signal=GPIO_Output
PD6.GPIO_Label=MODE_2
PD6.Signal=GPIO_Input
PD7.GPIO_Label=MODE_4
PD7.Signal=GPIO_Input
PD8.GPIO_Label=IMU_INT1
PD8.Signal=GPXTI8
PD9.GPIO_Label=IMU_INT2
PD9.Signal=GPXTI9
PE0.GPIO_Label=SERVO_EN
PE0.Signal=GPIO_Output
PE10.GPIO_Label=MAG_INT
PE10.Signal=GPXTI10
PE11.GPIO_Label=MAG_NSS
PE11.Signal=GPIO_Output
PE12.GPIO_Label=MAG_SCK
PE12.Signal=SPI4_SCK
PE13.Signal=SPI4_MISO
PE14.GPIO_Label=MAG_MOSI
PE14.Signal=SPI4_MOSI
PE4.GPIO_Label=EYE_0
PE4.Signal=GPIO_Output
PE5.GPIO_Label=EYE_1
PE5.Signal=GPIO_Output
PH0-OSC_IN.Signal=RCC_OSC_IN
PH1-OSC_OUT.Signal=RCC_OSC_OUT

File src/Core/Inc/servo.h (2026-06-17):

/*
 * servo.h
 *
 *  Created on: Mar 31, 2026
 *      Author: Sigmond
 */

#ifndef INC_SERVO_H_
#define INC_SERVO_H_

#include "state.h"

typedef struct {
	// PWM
	TIM_HandleTypeDef* tim_handle;
	// Power enable
	GPIO_TypeDef* en_gpio_port;
	uint16_t en_pin;
	// Feedback
	ADC_HandleTypeDef* adc_handle;
	volatile uint16_t* dma_buf;
	// Air brakes endpoints
	uint32_t duty_retracted;
	uint32_t duty_extended;
} servo_t;

// duty is the on time of the pulse (min 500 max 2500) [us]
void servo_set_duty(servo_t* servo, uint32_t duty) {

	global_state.servo_cmd = (float)(duty - 500) * (180.0f / (2500.0f - 500.0f)); // calculate servo cmd angle before clamping duty to expose issues

	// clamp duty to servo valid input
	if (duty < 500) {
		duty = 500;
	} else if (duty > 2500) {
		duty = 2500;
	}

	__HAL_TIM_SET_COMPARE(servo->tim_handle, TIM_CHANNEL_1, duty); // update PWM duty cycle
}

void servo_set_deployment(servo_t* servo, float deployment) {
	if (deployment < 0.0f) deployment = 0.0f;
	if (deployment > 1.0f) deployment = 1.0f;

	uint32_t duty = deployment * (float)(servo->duty_extended - servo->duty_retracted) + (float)(servo->duty_retracted);
	servo_set_duty(servo, duty);
}

// angle in deg
void servo_set_angle(servo_t* servo, float angle) {
	if (angle < 0.0f) angle = 0.0f;
	if (angle > 180.0f) angle = 180.0f;

	uint32_t duty = (uint32_t)((angle / 180.0f) * (2500 - 500) + 500);

	servo_set_duty(servo, duty);
}

// sig's mistake fixing
__attribute__((optimize("-O0"))) void servo_enable(servo_t* servo, uint8_t state)
{
	if (state == 1) { // state 1
		// need to ramp up voltage
		for (uint32_t i = 0; i < 5; i++) {
			servo->en_gpio_port->BSRR = servo->en_pin; // turn on
			// about 100 ns here
			servo->en_gpio_port->BSRR = (uint32_t)servo->en_pin << 16U; // turn back off

			// delay to slowly discharge the capacitance
			for (volatile uint32_t d = 0; d < 5000; d++) {
				__NOP();
			}
		}

		servo->en_gpio_port->BSRR = servo->en_pin; // turn on

	} else { // state is 0
		servo->en_gpio_port->BSRR = (uint32_t)servo->en_pin << 16U; // turn off
	}
}

void servo_init(servo_t* servo) {
	servo_enable(servo, 0);

	servo_set_duty(servo, 1520); // middle position

	// start PWM
	HAL_TIM_PWM_Start(servo->tim_handle, TIM_CHANNEL_1);

	// start continuous ADC
	HAL_ADC_Start_DMA(servo->adc_handle, (uint32_t*)servo->dma_buf, 1);
}

float servo_get_angle(servo_t* servo) {
	// 300mV for 0 degrees to 3000mV for 180 degrees
	// needs to be mapped into the ADC 0 to 4096 range
	// 300mV = 372 counts and 3000mV = 3724 counts

//	HAL_ADC_Start(servo->adc_handle);
//	HAL_ADC_PollForConversion(servo->adc_handle, 1);
//	uint32_t raw = HAL_ADC_GetValue(servo->adc_handle);

//	SCB_InvalidateDCache_by_Addr((uint32_t*)servo->dma_buf, 2);
	uint32_t raw = servo->dma_buf[0];

	// clamp to known voltage range (300 to 3000 mV)
	if (raw < 1130) {
		raw = 1130;
	} else if (raw > 3195) {
		raw = 3195;
	}

	// map the range (raw - counts_min) * (angle_max / counts_range)
	global_state.servo_fdbk = 180.0f - (float)(raw - 1130) * (180.0f / (3195.0f - 1130.0f));

	return global_state.servo_fdbk;
}

#endif /* INC_SERVO_H_ */

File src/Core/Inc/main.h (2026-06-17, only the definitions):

#define EYE_0_Pin GPIO_PIN_4
#define EYE_0_GPIO_Port GPIOE
#define EYE_1_Pin GPIO_PIN_5
#define EYE_1_GPIO_Port GPIOE
#define BATT_VSENSE_Pin GPIO_PIN_0
#define BATT_VSENSE_GPIO_Port GPIOC
#define BATT_ISENSE_Pin GPIO_PIN_1
#define BATT_ISENSE_GPIO_Port GPIOC
#define SERVO_FDBK_Pin GPIO_PIN_2
#define SERVO_FDBK_GPIO_Port GPIOC
#define BARO_NSS_Pin GPIO_PIN_4
#define BARO_NSS_GPIO_Port GPIOA
#define BARO_SCK_Pin GPIO_PIN_5
#define BARO_SCK_GPIO_Port GPIOA
#define BARO_MISO_Pin GPIO_PIN_6
#define BARO_MISO_GPIO_Port GPIOA
#define BARO_MOSI_Pin GPIO_PIN_7
#define BARO_MOSI_GPIO_Port GPIOA
#define BARO_INT_Pin GPIO_PIN_4
#define BARO_INT_GPIO_Port GPIOC
#define BARO_INT_EXTI_IRQn EXTI4_IRQn
#define MAG_INT_Pin GPIO_PIN_10
#define MAG_INT_GPIO_Port GPIOE
#define MAG_INT_EXTI_IRQn EXTI15_10_IRQn
#define MAG_NSS_Pin GPIO_PIN_11
#define MAG_NSS_GPIO_Port GPIOE
#define MAG_SCK_Pin GPIO_PIN_12
#define MAG_SCK_GPIO_Port GPIOE
#define MAG_MOSI_Pin GPIO_PIN_14
#define MAG_MOSI_GPIO_Port GPIOE
#define IMU_NSS_Pin GPIO_PIN_12
#define IMU_NSS_GPIO_Port GPIOB
#define IMU_SCK_Pin GPIO_PIN_13
#define IMU_SCK_GPIO_Port GPIOB
#define IMU_MISO_Pin GPIO_PIN_14
#define IMU_MISO_GPIO_Port GPIOB
#define IMU_MOSI_Pin GPIO_PIN_15
#define IMU_MOSI_GPIO_Port GPIOB
#define IMU_INT1_Pin GPIO_PIN_8
#define IMU_INT1_GPIO_Port GPIOD
#define IMU_INT1_EXTI_IRQn EXTI9_5_IRQn
#define IMU_INT2_Pin GPIO_PIN_9
#define IMU_INT2_GPIO_Port GPIOD
#define IMU_INT2_EXTI_IRQn EXTI9_5_IRQn
#define BTN_0_Pin GPIO_PIN_0
#define BTN_0_GPIO_Port GPIOD
#define BTN_0_EXTI_IRQn EXTI0_IRQn
#define BTN_1_Pin GPIO_PIN_1
#define BTN_1_GPIO_Port GPIOD
#define BTN_1_EXTI_IRQn EXTI1_IRQn
#define BTN_2_Pin GPIO_PIN_2
#define BTN_2_GPIO_Port GPIOD
#define BTN_2_EXTI_IRQn EXTI2_IRQn
#define BTN_3_Pin GPIO_PIN_3
#define BTN_3_GPIO_Port GPIOD
#define BTN_3_EXTI_IRQn EXTI3_IRQn
#define MODE_1_Pin GPIO_PIN_4
#define MODE_1_GPIO_Port GPIOD
#define MODE_C_Pin GPIO_PIN_5
#define MODE_C_GPIO_Port GPIOD
#define MODE_2_Pin GPIO_PIN_6
#define MODE_2_GPIO_Port GPIOD
#define MODE_4_Pin GPIO_PIN_7
#define MODE_4_GPIO_Port GPIOD
#define BUZZER_Pin GPIO_PIN_8
#define BUZZER_GPIO_Port GPIOB
#define SERVO_SIG_Pin GPIO_PIN_9
#define SERVO_SIG_GPIO_Port GPIOB
#define SERVO_EN_Pin GPIO_PIN_0
#define SERVO_EN_GPIO_Port GPIOE
#define W25Q_TIMEOUT_VALUE 100 // [ms]

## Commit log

2025-01-19 Initial commit
    Loads all previous work into Git.
    As it stands: PCB is largely laid out, but missing a few sensors. Not all values are specified in the schematic yet, and also missing a few sensors. Not yet ready for production.
    [Motion.kicad_sch, Servo.kicad_sch, airbrake_mod.kicad_pcb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]
2025-01-27 Power Supply Speccing, IMU, Eyeballs
    [airbrake_mod.kicad_pcb, mcu.kicad_sch, power.kicad_sch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]
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2025-02-19 Release Candidate 2
    Incorporates fixes for all identified issues in the PCBR
    [airbrake_mod.kicad_pcb, mcu.kicad_sch, power.kicad_sch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]
2025-02-20 Release Candidate 3
    Fixed name, one location with vias. Added production files in prep for merge request.
    [airbrake_mod-B_Cu.gbr, airbrake_mod-B_Mask.gbr, airbrake_mod-B_Paste.gbr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]
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2025-10-08 Change to 4 layer stackup
    [airbrake_mod.kicad_pcb]
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2025-11-03 Add TI buck converter to power
    [mcu.kicad_sch, power.kicad_sch, usb.kicad_sch]
2025-11-03 Begin power tree design
    [airbrake_mod.kicad_sch, mcu.kicad_sch, power.kicad_sch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]
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2025-11-04 Implement flash memory connection
    [airbrake_mod.kicad_sch, flash.kicad_sch, mcu.kicad_sch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]
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2025-11-05 Add servo supporting info
    [airbrake_mod.kicad_sch, servo.kicad_sch]
2025-11-05 Add comments for buck passives
    [power.kicad_sch]
2025-11-05 Draw battery switch PMOS driver
    [power.kicad_sch, servo.kicad_sch]
2025-11-07 Finish and simplify power schematics
    [power.kicad_sch]
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2025-11-08 Update sensors.kicad_sch
    Added LPS22DF schematic
    [sensors.kicad_sch]
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2025-11-10 Connected LSM6DSV80X IMU to SPI
    [sensors.kicad_sch]
2025-11-10 Connected sensors SPI bus and signals to MCU
    [airbrake_mod.kicad_sch, mcu.kicad_sch, sensors.kicad_sch]
2025-11-13 Add 3D model to XT30 connector
    [debug.kicad_sch, power.kicad_sch]
2025-11-13 Add rotary switch to user interface
    [user_interface.kicad_sch]
2025-11-17 Adjust flash diagram to make room for pullups
    [debug.kicad_sch, flash.kicad_sch]
2025-11-17 Add buzzer symbol to user interface
    [user_interface.kicad_sch]
2025-11-17 Cleaned up power sheet
    [power.kicad_sch]
2025-11-17 Move IMU to the left to accommodate magnetometer
    [sensors.kicad_sch]
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2025-11-17 Add buzzer and move servo
    Buzzer - TIM16 CH1 PB8
    Servo - TIM17 CH1 PB9
    SERVO_EN PE0
    [airbrake_mod.kicad_sch, mcu.kicad_sch, sensors.kicad_sch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]
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2025-11-17 Enable TIM3 and TIM4 for status LEDs
    [airbrake_mod.kicad_sch, mcu.kicad_sch]
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2025-11-17 Add hierarchical labels for mode switch and user buttons
    [mcu.kicad_sch, user_interface.kicad_sch]
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2025-11-17 Updated batt sense voltage divider
    [power.kicad_sch]
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2025-11-22 Decrease LED current from 15 mA to 10 mA per color
    [user_interface.kicad_sch]
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2025-11-23 Finish routing with rotated STM32
    [airbrake_mod.kicad_pcb, debug.kicad_sch, mcu.kicad_sch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]
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2025-11-23 Incorporate feedback servo with 4 pin molex and additional ADC channel
    [airbrake_mod.kicad_pcb, airbrake_mod.kicad_sch, debug.kicad_sch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]
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2025-11-23 Add back ground plane
    [airbrake_mod.kicad_pcb]
2025-11-23 Add plating to mounting holes
    [airbrake_mod.kicad_pcb]
2025-11-23 Push analog channels to the right a little
    [airbrake_mod.kicad_pcb]
2025-11-23 Remove extra silkscreen text
    [airbrake_mod.kicad_pcb]
2025-11-23 Specify SPDT for buck enable
    [power.kicad_sch]
2025-11-23 Add buck enable switch
    [airbrake_mod.kicad_pcb, debug.kicad_sch, flash.kicad_sch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]
2025-11-24 Add buck converter inductor 3D model
    [airbrake_mod.kicad_pcb, mcu.kicad_sch]
2025-11-24 Add 3D models for B38G3RGB
    [airbrake_mod.kicad_pcb]
2025-11-24 Tune high speed routing
    [airbrake_mod.kicad_pcb]
2025-11-24 Move switch further from USB C
    [airbrake_mod.kicad_pcb]
2025-11-25 Add ESD protection diode arrays
    [airbrake_mod.kicad_pcb, debug.kicad_sch]
2025-11-26 Move crystal closer to MCU
    [airbrake_mod.kicad_pcb]
2025-11-26 Tweak decoupling capacitor routing
    [airbrake_mod.kicad_pcb]
2025-11-26 Add 3D model for test point
    [airbrake_mod.kicad_pcb]
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2025-11-26 Annotate buck EN details
    [power.kicad_sch]
2025-11-26 Disable DNP for NRST capacitor
    [mcu.kicad_sch]
2025-11-26 Annotate "no LSE" on MCU schematic
    [mcu.kicad_sch]
2025-11-27 Add CUR schematic sheet title block
    [airbrake_mod.kicad_sch, debug.kicad_sch, flash.kicad_sch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]
2025-11-27 Add CUR logo to all schematic sheets
    [airbrake_mod.kicad_sch, debug.kicad_sch, flash.kicad_sch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]
2025-11-29 Add user labels and PTH mechanical connections
    [airbrake_mod.kicad_pcb]
2025-12-01 Enabled and implemented VBUS LED
    [airbrake_mod.kicad_pcb, usb.kicad_sch]
2025-12-06 Add production files for quoting
    [Air Brakes 25-26 BOM.xlsx, airbrake_mod.kicad_pcb, airbrake_mod.kicad_sch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]
2025-12-13 Add remaining signatures to PCB
    [airbrake_mod.kicad_pcb, debug.kicad_sch]
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2025-12-14 Add MPN field for components except resistors
    [airbrake_mod.kicad_sch, alex_black_eyes.kicad_sch, debug.kicad_sch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]
2025-12-14 BOM optimize RGB LED resistors
    50 ohm current limiting resistors on G/B channels -> 47 ohm to match MCU VREF+
    [user_interface.kicad_sch]
2025-12-14 BOM optimize 100 ohm resistors to 150 ohm
    [debug.kicad_sch, power.kicad_sch, servo.kicad_sch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]
2025-12-14 BOM optimize GNDDetect 100 ohm resistor to 150 ohm
    [debug.kicad_sch]
2025-12-14 Fix MCU position
    It was tweaked off to the side
    This reverts that change from a week ago
    [airbrake_mod.kicad_pcb]
2025-12-14 BOM optimize VBUS LED
    600R to 3x 150R = 450R for 6.667 mA
    [airbrake_mod.kicad_pcb, power.kicad_sch, usb.kicad_sch]
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2025-12-14 Update MPNs to optimize for HQ Online
    [Air Brakes 25-26 BOM.xlsx, airbrake_mod.kicad_pcb, flash.kicad_sch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]
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2025-12-14 Add gerbers uploaded to NextPCB
    [airbrake_mod-B_Cu.gbr, airbrake_mod-B_Mask.gbr, airbrake_mod-B_Paste.gbr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]
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2025-12-15 Add CUR logo to alex black eyes sheet
    [alex_black_eyes.kicad_sch]
2025-12-15 Fix buck EN
    [airbrake_mod.kicad_pcb, power.kicad_sch]
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2025-12-15 Replace RGB LED symbol in user interface schematic
    [user_interface.kicad_sch]
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2025-12-15 Remove old RGB LEDs and reroute VBUS detect
    [airbrake_mod.kicad_pcb]
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2025-12-15 Replace B1911USD LED with equivalent FC-1608SXK-620H08
    [airbrake_mod.kicad_pcb, alex_black_eyes.kicad_sch, usb.kicad_sch]
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2025-12-17 Fix QSPI IO0/IO1 swap
    [airbrake_mod.kicad_pcb, mcu.kicad_sch]
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2025-12-21 Replace inductor with HQOnline alternative
    [airbrake_mod.kicad_pcb, power.kicad_sch]
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2025-12-22 Tweak BOOT and RESET routing
    [airbrake_mod.kicad_pcb]
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2026-04-15 Fix servo angle feedback
    [servo.h]
2026-04-15 Replace ADC polling with DMA for batt sense
    [airbrake_mod.ioc, batt_sense.h, main.c]
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2026-04-15 Fix sensor to body rotations and decrease beta
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2026-04-16 Fix servo power on brownout
    [servo.h]
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2026-05-10 Add UART error callback that restarts the UART in case of overrun
    [main.c]
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2026-06-07 Broadly replace telemetry_log with printf
    [flash.c, sensors.c]
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2026-06-09 Fix components import path in app
    [app.py]
2026-06-13 Replace lockouts with flags
    [main.c]
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2026-06-17 Replace custom flash driver with W25Q driver
    [flash.c, main.c]
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

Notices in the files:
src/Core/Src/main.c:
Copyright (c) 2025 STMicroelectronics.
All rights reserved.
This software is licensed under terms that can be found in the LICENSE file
